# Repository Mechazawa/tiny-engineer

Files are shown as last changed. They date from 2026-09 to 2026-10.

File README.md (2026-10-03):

# Tiny Engineer

> Give your AI coding agent a body.

Tiny Engineer demo

**[Watch the demo](https://youtu.be/RX_QRxdXMjg)** · [Build your own](#build-your-own) · [Community builds](#community-builds) · [How it works](#how-it-works)

A small robot on your desk. It moves, changes its face, and rings a bell as your coding AI agent works.

| Your agent… | The robot… |
| --- | --- |
| Reads files | Looks around |
| Writes code | Types |
| Thinks or waits | Looks up |
| Finishes the task | Rings the bell |

Open source. Print the body, plug the ESP32, servos, OLED, and speaker into the [main control board](docs/hardware/main-control-board.md), flash it, and it joins your Wi-Fi.

**Works with** [Claude Code](docs/integration.md#4-claude-code-dedicated-script) · [Cursor](docs/hooks.md) · [Antigravity](docs/integration.md#3-antigravity-cli-dedicated-script) — or Codex, Windsurf, and any script that can POST ([integration guide](docs/integration.md)).

## Build your own

| | |
| --- | --- |
| **Parts (electronics + 5× SG90 Servos)** | [shopping list](docs/shopping.md): [main control board](docs/hardware/order-main-control-board.md) plus ESP32, servos, OLED, and speaker |
| **Also needed** | 3D printer + filament, or [order prints](docs/3d/order-parts.md); M2 screws; **5 V / ≥2 A** USB supply |
| **Tools** | Plug in the ESP32, servos, OLED, and speaker on the [main control board](docs/hardware/main-control-board.md). Want to add extra modules? [advanced wiring](docs/hardware/wiring.md) |
| **Difficulty** | **Medium** - fair first hardware project for a software engineer, not a one-LED kit. Optional primer: [From Code to Circuits](docs/hardware-for-software-engineers/README.md) |

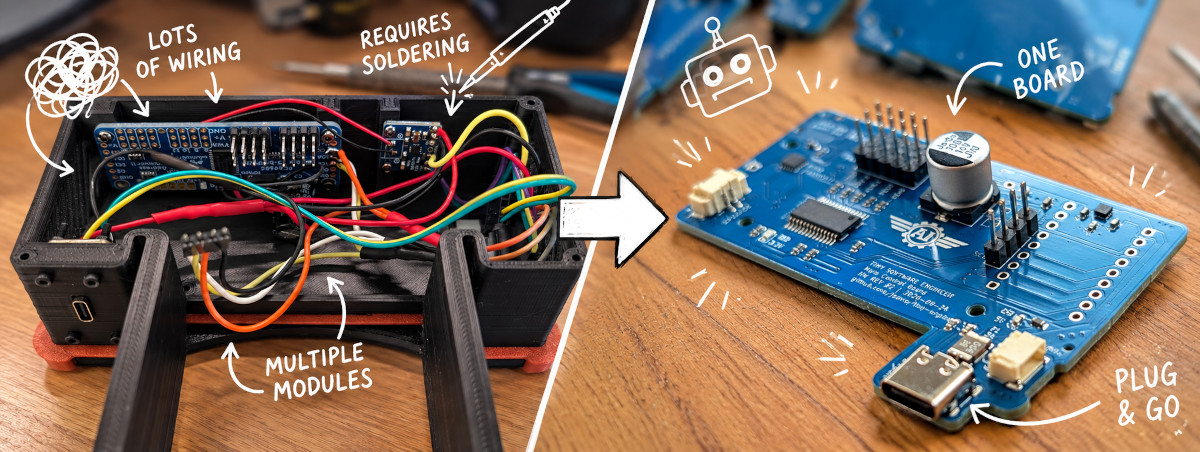
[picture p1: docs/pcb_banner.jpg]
Main control board (https://github.com/jamro/tiny-engineer/discussions/50)


The default build uses the open-source main control board. Order it from any fab ([how to order](docs/hardware/order-main-control-board.md) · [KiCad](hardware/boards/main-control-board/)). A ~$15–20 assembled board would be easier to buy. [Vote here 👍 →](https://github.com/jamro/tiny-engineer/discussions/50)

**Print → Connect → Flash → Assemble** - step-by-step: **[Getting started](docs/getting-started.md)**.

## Community builds

Built Tiny Engineer

Finished builds, mods, and desk setups live in **[Show and tell](https://github.com/jamro/tiny-engineer/discussions/categories/show-and-tell)** on GitHub Discussions - browse what others made and post photos of yours.

**Built one? [Share in Show and tell →](https://github.com/jamro/tiny-engineer/discussions/categories/show-and-tell)**

## Roadmap

What we are building toward:

- **More agent integrations** - one-command hooks for more IDEs and CLIs
- **Simplified build process** - easier assembly and setup for quicker builds
- **New characters / bodies** - alternate shells and mods
- **Multi-agent desk** - more than one tiny teammate

**[Star Tiny Engineer](https://github.com/jamro/tiny-engineer)** to follow the build.

## How it works

How Tiny Engineer works

Your agent (or a hook script) sends poses over HTTP. The **ESP32-C3** is a small Wi-Fi computer on the robot — one chip that runs the program, joins your network, hosts REST API, and drives the servos, the face, and the speaker.

**Clients**

- **Cursor** - hooks → `tiny-engineer-cursor` → Wi-Fi
- **Antigravity** - lifecycle hooks → `tiny-engineer-antigravity` → Wi-Fi
- **Claude Code** - project hooks → `tiny-engineer-claude-code` → Wi-Fi
- **Bring your own** - any tool that can `POST` to `/anim`

Details: [Integrations](docs/integration.md) · [HTTP API](docs/api.md) · [Cursor hooks](docs/hooks.md)

## Documentation

| You want to… | Start here |
| --- | --- |
| Build the robot | [Getting started](docs/getting-started.md) |
| Buy parts | [Shopping list](docs/shopping.md) |
| Flash the board | [Flash](docs/flash.md) |
| Assemble the prints | [Assembly](docs/3d/assembly.md) |
| Print the parts | [3D models](3d_models/README.md) |
| Hook up an agent | [Integrations](docs/integration.md) |
| Call the HTTP API | [API](docs/api.md) |
| Anything else | [Docs index](docs/README.md) |

Print it, connect it, change the CAD, or hook up another agent. Issues and PRs welcome - especially new integrations. [CONTRIBUTING.md](CONTRIBUTING.md) · [SECURITY.md](SECURITY.md) · [CODE_OF_CONDUCT.md](CODE_OF_CONDUCT.md)

## License

- **Software** (firmware, integrations, scripts, documentation) — [MIT](LICENSE)
- **Hardware designs** (CAD source and printables in [`3d_models/`](3d_models/) and under [`mods/*/3d_models/`](mods/); KiCad PCBs in [`hardware/`](hardware/)) — [CERN-OHL-S-2.0](3d_models/LICENSE)

See [LICENSING.md](LICENSING.md) for scope and effective date. The **Tiny Engineer** name and logo are not licensed - see [TRADEMARK.md](TRADEMARK.md).

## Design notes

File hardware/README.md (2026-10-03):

# Hardware (PCB)

KiCad PCB projects for Tiny Engineer. Builders: the main control board is the default electronics path — [shopping](../docs/shopping.md) and [connect guide](../docs/hardware/main-control-board.md). Breakout modules are an advanced path for extra hardware the board does not support — [wiring](../docs/hardware/wiring.md).

Boards live under `boards/<board-name>/`. Prefer the same name for the directory and the KiCad project.

| Board | Role |
| --- | --- |
| [`main-control-board`](boards/main-control-board/) | Main board: PCA9685, MAX98357A, and USB-C on the board; ESP32-C3-Zero plugs into two sockets |

Contribution rules, KiCad version, what to commit, ERC/DRC, and PR expectations: [docs/pcb.md](../docs/pcb.md). Pre-PR checklist: [docs/pcb.md#checklist](../docs/pcb.md#checklist). Critical net checklist: [docs/pcb.md#expected-netsyml](../docs/pcb.md#expected-netsyml). Local/CI checks: `python3 scripts/check_pcb.py` (KiCad 10) — [docs/testing.md](../docs/testing.md).

This tree is KiCad source only. Robot electrical reference (pinout, wiring, BOM) is [`docs/hardware/`](../docs/hardware/README.md). Firmware drivers are `src/hardware/`.

## License

Board sources in `boards/` are [CERN-OHL-S-2.0](LICENSE). See [NOTICE](NOTICE) for copyright, Source Location, and product notice requirements.

This README is software documentation and remains under the MIT License — [LICENSING.md](../LICENSING.md).

The **Tiny Engineer** name and logo are not licensed — [TRADEMARK.md](../TRADEMARK.md).

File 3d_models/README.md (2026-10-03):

# 3D models

Printable parts and source CAD for the Tiny Engineer desk robot.

## Source CAD (edit / resize)

The full assembly — all components composed — lives in [`cad/TinyEngineer.f3d`](cad/TinyEngineer.f3d) (Autodesk Fusion). Open that file to adjust the model or adapt it to different hardware sizing (e.g. different servos). Parametric servo sizes and the Fusion add-in: [docs/3d/parametric-design.md](../docs/3d/parametric-design.md).

**Adding a new part** (parametric rules, timeline, `PRINT_LAYOUT`, Servo Configurator, export, optional mods): [docs/3d/adding-parts.md](../docs/3d/adding-parts.md). Optional / community mods: [`mods/`](../mods/).

## Printables

Individual parts are exported under [`parts/{servo_id}/`](parts/). Match the folder to the servos you bought ([which servo](../docs/shopping.md)). `stl/` next to `3mf/` is the same mesh in binary STL. `step/` next to those is CAD interchange (BRep STEP), not a printable mesh for a home slicer.

Two ways to get the mechanical set (same place in the build path):

- **Print yourself** — use the **`.3mf` files in `parts/sg90/3mf/`**, **`parts/fs0307/3mf/`**, or **`parts/hd1370a/3mf/`**. Ready to print in an orientation that does not need supports. **PLA** or **PETG**. Start with [Print first](#print-first).
- **No printer?** — order the aggregated sets from a third-party service: [order printed parts](../docs/3d/order-parts.md). Orders are at your own risk; fit can vary by provider and design revision.

### Print first

**Home printers only.** Print these two small testers from that folder **before** the rest of the set. Do not print the full robot until both fit. Skip this step when ordering from a service (testers alone are rarely worth the min fee + shipping).

1. **`ServoSizingTester.3mf`** — seat a real servo; do not force it. The body should slide, tabs sit, holes line up, and the shaft should have clearance. Tight or loose → sand/ream, or adjust servo CAD params ([parametric design](../docs/3d/parametric-design.md)).
2. **`ScrewSizingTest.3mf`** — M2 screw pilot-hole tolerance. Each hole is marked with its diameter. Drive an M2 screw into each hole and pick the tightest size that still cuts a thread (does not spin freely / slide through). Set Fusion user parameter `screw_thread_diameter` to that marked value, then re-export before printing structural parts. Details: [M2 screw holes](../docs/3d/parametric-design.md#m2-screw-holes).

Assembly uses **M2 screws** that thread directly into the printed PLA/PETG — no glue, no heat-set inserts. Easy to dismount and modify later. Buyer cart (electronics + screw qty + supply): [docs/shopping.md](../docs/shopping.md). Overall build order: [docs/getting-started.md](../docs/getting-started.md). Mechanical procedure: [docs/3d/assembly.md](../docs/3d/assembly.md). Per-step lengths: [screw list](#screws) below.

### Screws

**Spec:** M2 thread-forming (self-tapping) screws for plastic, **pan-head or button-head** — heads normally sit on the plastic surface. `BottomCover` has recessed head pockets; use heads no larger than **4.0 mm diameter × 2.0 mm high** so the underside rests flat. CAD default pilot is **2.1 mm** (Fusion user parameter `screw_thread_diameter`); if your `ScrewSizingTest` winner differs, re-export at that diameter before printing structural parts. Details: [M2 screw holes](../docs/3d/parametric-design.md#m2-screw-holes).

**One BOM for every servo preset** (`parts/sg90/`, `parts/fs0307/`, `parts/hd1370a/`, …). Printed parts scale with the servo choice, but the lengths below are the reference list for all of them — including smaller models for smaller servos. Buy quantities: [docs/shopping.md](../docs/shopping.md). Pilots are cut as deep as practical so nearby lengths often work too; if you already have different M2 lengths, test-fit before buying a full set. Per-step placement: [assembly guide](../docs/3d/assembly.md).

**Per robot (qty is source of truth):**

| Item | Qty | Typical use |
| --- | --- | --- |
| M2×4 mm | 8 | Emblem, PCA9685, MAX98357A |
| M2×8 mm | 27 | Hat, Neck↔Head, Chest center (prefer two), Belly↔Chest, LampBase, laptop, mug, Chair↔Desk, elbows, BottomCover ×6 |
| M2×16 mm | 15 | Chest side servos, SeatLeft/Right, DeskTop stack, USB-C, Bell |
| M2 nuts | 6 | Neck captured ×1, USB-C ×4, Bell ×1 |
| Servo bag screws | 5 | Neck shaft, Neck↔Head (robot’s left), Belly shaft, both arms |

Prefer **two** M2×8 for the Neck servo in `Chest`; one at the back is enough if space is tight (buy 27 either way). An M2 assortment covering **M2×4–M2×16** is the easy path.

## Parts

Same filenames in each `parts/{servo_id}/3mf/` folder (and matching `stl/` / `step/`):

| File | Role |
| --- | --- |
| `PartsSetA.3mf` | Aggregated copper-color group for [service orders](../docs/3d/order-parts.md) (home print: use individuals below) |
| `PartsSetB.3mf` | Aggregated black-color group for [service orders](../docs/3d/order-parts.md) (home print: use individuals below) |
| `Head.3mf` | Head (pitch) |
| `Neck.3mf` | Neck (yaw) |
| `ForearmLeft.3mf` | Left forearm / hand |
| `ForearmRight.3mf` | Right forearm / hand |
| `UpperArm.3mf` | Upper arm |
| `Chest.3mf` | Chest / torso |
| `Belly.3mf` | Belly |
| `Chair.3mf` | Chair |
| `SeatLeft.3mf` | Left chair seat |
| `SeatRight.3mf` | Right chair seat |
| `Desk.3mf` | Desk structure |
| `BottomCover.3mf` | Underside cover; six M2×8 (four desk, two chair) |
| `DeskTop.3mf` | Desk top surface |
| `DeskPad.3mf` | Desk pad |
| `LaptopCase.3mf` | Miniature laptop body |
| `LaptopScreen.3mf` | Laptop screen |
| `Bell.3mf` | Service bell |
| `LampBase.3mf` | Desk lamp base |
| `LampCap.3mf` | Lamp cap |
| `LampDiffuser.3mf` | Lamp diffuser |
| `LampButton.3mf` | Lamp button |
| `Mug.3mf` | Mug |
| `Coffee.3mf` | Coffee fill |
| `Hat.3mf` | Hat |
| `ServoSizingTester.3mf` | Servo pocket fit tester |
| `ScrewSizingTest.3mf` | M2 screw pilot-hole diameter tester |
| `AiEmblem.3mf` | AI emblem detail |

## Next steps

Return to the build checklist: [docs/getting-started.md](../docs/getting-started.md) ([§2 Print or order](../docs/getting-started.md#2-print-or-order) done). Connect and flash **before** opening the mechanical guide.

1. Connect, then flash: [docs/hardware/main-control-board.md](../docs/hardware/main-control-board.md), [docs/flash.md](../docs/flash.md). Extra modules: [docs/hardware/wiring.md](../docs/hardware/wiring.md)
2. Assemble in one run: [docs/3d/assembly.md](../docs/3d/assembly.md)
3. Servo axes and safe ranges: [docs/robot-movement.md](../docs/robot-movement.md)
4. Bring-up and failures: [docs/hardware/testing.md](../docs/hardware/testing.md)

## License

CAD source (`.f3d`) in [`cad/`](cad/) and printable parts (`.3mf`) in [`parts/`](parts/) are licensed under [CERN-OHL-S-2.0](LICENSE). See [NOTICE](NOTICE) for copyright, Source Location, and product notice requirements.

Commercial use is allowed. If you modify and distribute Products based on these designs, reciprocal provisions require sharing your Complete Source under the same license. This documentation file is software documentation and remains under the MIT License — see [LICENSING.md](../LICENSING.md).

The **Tiny Engineer** name and logo are not licensed — see [TRADEMARK.md](../TRADEMARK.md).

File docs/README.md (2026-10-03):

# Docs index

Pick a path. Depth lives in the linked pages.

### Building the robot

| You want to… | Start here |
| --- | --- |
| **Build from scratch** (canonical checklist) | [getting-started.md](getting-started.md) |
| **Buy parts** (main control board + cart) | [shopping.md](shopping.md) |
| **Bridge into hardware/electronics** (software engineer background) | [hardware-for-software-engineers/README.md](hardware-for-software-engineers/README.md) — optional parallel reading; safety card lives on the checklist |
| **Assemble printed parts** (mechanical procedure) | [3d/assembly.md](3d/assembly.md) |
| **Flash firmware** | [flash.md](flash.md) |
| **Electronics** (main control board) | [shopping.md](shopping.md) → [hardware/main-control-board.md](hardware/main-control-board.md) → [hardware/README.md](hardware/README.md) |
| **Extra modules** (advanced breakouts) | [shopping.md](shopping.md#advanced-extra-modules) → [hardware/wiring.md](hardware/wiring.md) → [3d/assembly-modular.md](3d/assembly-modular.md) |
| **Print / parts inventory** | [../3d_models/README.md](../3d_models/README.md) |
| **Order printed parts** (no 3D printer) | [3d/order-parts.md](3d/order-parts.md) |
| **Order main control board** (PCB / PCBA) | [hardware/order-main-control-board.md](hardware/order-main-control-board.md) |
| **Adapt CAD to a different servo** | [3d/parametric-design.md](3d/parametric-design.md) |
| **Add a new CAD / printable part** | [3d/adding-parts.md](3d/adding-parts.md) |
| **Optional mods** | [../mods/README.md](../mods/README.md) |
| **Use with an agent** (robot already on Wi-Fi) | [integration.md](integration.md) · Cursor: [hooks.md](hooks.md) |

### Reference and contribute

| You want to… | Start here |
| --- | --- |
| **Contribute a PCB** (KiCad) | [pcb.md](pcb.md) → [`hardware/`](../hardware/README.md) |
| **HTTP API / settings** | [api.md](api.md); add a setting: [settings.md](settings.md) |
| **Any IDE / scripts** | [integration.md](integration.md) |
| **Firmware / package tests** | [testing.md](testing.md) |
| **AI coding agents (repo rules)** | [AGENTS.md](../AGENTS.md) |
| **Contribute / report a vuln** | [CONTRIBUTING.md](../CONTRIBUTING.md); [SECURITY.md](../SECURITY.md) |
| **Share a finished build** | [Show and tell](https://github.com/jamro/tiny-engineer/discussions/categories/show-and-tell) — [how to post](../CONTRIBUTING.md#share-your-build) |

Also: [robot-movement.md](robot-movement.md) (servo axes and safe ranges); optional [macos-lock-unlock.md](macos-lock-unlock.md) (sleep/wake on Mac screen lock).

**Source of truth:** pin constants in firmware (`include/pins.h`); electrical detail in `docs/hardware/`; HTTP shapes in [api.md](api.md). Overall build order: [getting-started.md](getting-started.md).

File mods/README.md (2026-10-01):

# Mods

Optional add-ons for Tiny Engineer. Stock robot parts live in [`3d_models/`](../3d_models/).

A mod can hold models and anything else (notes, images, firmware snippets). Printable geometry and Fusion source stay under that mod’s `3d_models/` folder.

## Layout

```text
mods/<mod_name>/
  README.md              # optional: what it is, non-model notes
  3d_models/
    cad/                 # Fusion source, when the mod has one
    parts/{servo_id}/    # exports; same idea as 3d_models/parts/
  ...                    # anything that is not a model
```

`parts/{servo_id}/` mirrors stock: `3mf/`, `stl/`, and `step/`. Example: [`halloween/`](halloween/).

## Audio

Optional speaker replacements live in `mods/<mod_name>/assets/`. Format matches stock: **44100 Hz, mono, 16-bit PCM**. Firmware still plays `/welcome.wav` and the other root names. The build overlay copies stock [`assets/`](../assets/) first, then overwrites any basename the mod ships. A missing file stays the stock clip.

Set the mod in [`platformio.ini`](../platformio.ini) (`custom_audio_mod = halloween`) and flash with `pio run -t upload`. An empty option keeps the stock image. How to flash: [docs/flash.md](../docs/flash.md).

Clips with phrase marks (`welcome`, `attention`, `error`, `abort`, `dead`) need a sibling `.cue` next to the replacement WAV. `bell` has no marks. A cue without its WAV is rejected. Lines are `key=ms` (`#` comments allowed). `end_ms` must be within 200 ms of the WAV duration, phases must increase, and a blink must sit inside its window. The pack step checks this before the image is built.

Firmware loads `/welcome.cue` (and the other clip names) from LittleFS at boot. A missing or invalid file keeps the stock marks compiled into the firmware. Editing a `.cue` and running `pio run -t uploadfs` changes timing without a gesture-code change.

| Clip | Keys, in phase order |
| --- | --- |
| `welcome` | `greeting_end_ms`, `pause_end_ms`, `question_end_ms`, `end_ms`. Blink: `blink_start_ms`, `blink_end_ms` inside greeting→pause. |
| `attention` | `pst_end_ms`, `human_end_ms`, `end_ms`. Blink inside pst→human. |
| `error` | `uhoh_end_ms`, `human_end_ms`, `problem_end_ms`, `end_ms` |
| `abort` | `fine_end_ms`, `didnt_want_end_ms`, `finish_end_ms`, `end_ms` |
| `dead` | `dense_ms`, `shutdown_ms`, `end_ms` |

## Workflow

Design, timeline, `PRINT_LAYOUT`, export, and checklist: [docs/3d/adding-parts.md](../docs/3d/adding-parts.md).

## Commits

`type(mods): summary`. Name the mod in the summary (`feat(mods): add desk clamp`). One scope for every mod. `feat(mods)` / `fix(mods)` do not version the stock CAD revision. Moving a mod into stock [`3d_models/cad/`](../3d_models/cad/) and [`3d_models/parts/`](../3d_models/parts/) is `feat(cad)`. Full rules: [CONTRIBUTING.md](../CONTRIBUTING.md).

## License

CAD and manufacturing exports under `mods/<mod_name>/3d_models/{cad,parts}/` are [CERN-OHL-S-2.0](../3d_models/LICENSE). See [NOTICE](../3d_models/NOTICE) for warranty and product-notice requirements.

When you distribute a Product based on a mod, cite that licence and use the mod’s own `3d_models` tree as the Source Location (for example `https://github.com/jamro/tiny-engineer/tree/main/mods/halloween/3d_models`).

This README and other files beside `3d_models/` are documentation under the [MIT License](../LICENSE).

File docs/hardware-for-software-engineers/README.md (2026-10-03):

# From Code to Circuits: Hardware for Software Engineers

*Learn electronics and physical builds through Tiny Engineer — a desk robot that's fun to finish and honest about real hardware.*

I wrote this because software engineers keep asking how to build Tiny Engineer when they've never touched the hardware side — what's a servo driver, why two voltages, whether they'll destroy the board on first power-on. The build docs tell you *what to connect*; this guide answers the questions behind them.

---

## Goal

**Bring the world of electronics and hardware closer to software engineers** — especially the ones showing up with Tiny Engineer parts and no hardware background.

If you live in code, hardware docs can feel like a foreign API with no types and no stack traces. This guide closes that gap: same systems thinking you already use — buses, power budgets, failure modes — applied to volts, GPIO, and printed plastic. It's the long-form version of answers I give when someone says *"I'm a developer, I just want the robot to work."*

**Why now:** AI makes writing code fast and cheap. Hardware stays tangible, constrained, and extremely satisfying when something on your desk actually moves because *you* wired it.

**Why Tiny Engineer as the example:** one coherent stack (MCU, I2C, I2S, power domains, 3D print, servos) — real enough to teach honest hardware, bounded enough to finish if you stick with it. It also ties back to software via Wi-Fi and HTTP, which helps the mental bridge.

**What you'll get out of it:** read datasheets, schematics, and embedded docs without feeling like an outsider — whether you build this robot or the next board on your bench.

**Honest expectation:** Tiny Engineer was never meant to be an entry-level electronics kit (no single-LED breadboard tutorial). Overall difficulty is **medium**. It can still be your **first hardware project** as a software engineer — if you read alongside the build, smoke-test the main control board on the desk (connect + flash) before closing the shell, and don't treat "first" as "trivial." Harness examples later in this guide are the advanced path for extra modules — [wiring.md](../hardware/wiring.md). See [difficulty by area](#honest-difficulty-by-area) below.

---

I'm a software engineer. I got into hardware and electronics long before Tiny Engineer — out of curiosity, because I find it fun, and because making something *physical* work hits different from shipping another service. I'm not an EE. I've smelled the regret breadboard too; I've also had plenty of projects since then that actually moved and blinked.

Tiny Engineer is one project in that line. I'd recommend this path to any software engineer: learn the basics, wire something on a bench, watch it do a thing you commanded. Especially now, when a servo buzzes because you misaligned a horn — not because a model hallucinated a pin number — you learn something no codegen session replaces.

**What this is:** a bridge into electronics, microcontrollers, power, protocols, and mechanical build craft — taught with software-engineer mental models.

**What this is not:** only a Tiny Engineer assembly manual. When you're ready to build step by step, use [getting-started.md](../getting-started.md) (checklist), [flash.md](../flash.md), and the [hardware reference](../hardware/README.md).

---

## Why Tiny Engineer is the example

Every chapter teaches a **general concept**, then shows **where it lands in this build**. Tiny Engineer gives you real constraints — 3.3 V vs 5 V domains, shared I2C, offloaded servo PWM, print tolerances, antenna keep-out — without throwing you into a parts warehouse with no narrative. Finish the robot if you want the payoff; the vocabulary transfers to other ESP32, Arduino, or IoT projects either way.

It's a good **first hardware project for a software engineer**. It is **not** a good **first project in electronics** in the abstract — compare it to a blinking-LED kit and this is several notches up. This guide exists because those two truths collide constantly in questions from SWEs who want to build the robot anyway.

---

## Honest difficulty by area

Rough levels: **Easy** · **Medium** · **Medium–High** (for someone with no prior hardware builds). Overall build: **Medium**.

| Area | Level | Why |
| --- | --- | --- |
| [Electricity & power domains](01-electricity-and-units.md) | Medium | Two voltage rails, common GND, VCC vs V+ — mistakes fry boards, not just fail tests |
| [Microcontrollers & ESP32](02-microcontrollers-and-esp32.md) | Medium | Wi-Fi MCU, native USB, scarce GPIO, flash/LittleFS — more moving parts than Arduino Uno 101 |
| [Wiring & schematics](03-wiring-craft-and-schematics.md) | Medium–High | Default board is plug-in. The advanced harness is six-ish modules, many nets, classic traps (swapped I2C, speaker on GND) |
| [Buses: I2C, I2S, PWM](04-buses-and-protocols.md) | Medium | Three protocol types in one device; standard hobby stack, but not "one wire one LED" |
| [Servos & mechanical motion](05-servos-and-mechanical-motion.md) | Medium–High | Five joints, horn alignment, mechanical limits, binding/stall — software clamps can't fix physics |
| [3D printing & mechanical build](06-3d-printing-and-mechanical-build.md) | Medium | Many printed parts, tolerances, partial assembly docs; optional Fusion edits add learning curve |
| [Power budgets & safety](07-power-budgets-and-safety.md) | Medium | Real stall currents (~1.3–1.6 A), supply sizing, brownout debugging |
| [Embedded workflow & debug](08-tools-debugging-and-embedded-workflow.md) | Medium *(lower if you live in CLI)* | PlatformIO, serial, bisect bring-up — familiar shape for SWEs, unfamiliar failure modes |
| REST / Wi-Fi / agent hooks | Easy *(for SWEs)* | HTTP you already know — **after** hardware works |

**What makes it medium, not beginner-kit:**
- Multiple ICs on shared buses, not one chip
- Motor power + logic power discipline
- Mechanical assembly with real tolerances
- Debug requires dividing hardware vs software

**What makes it viable as a first SWE hardware project:**
- Documented BOM, wiring, firmware — not a blank breadboard
- Software-shaped affordances: serial logs, HTTP `/test/*`, web UI
- This guide translates concepts into your vocabulary first
- Finish line is motivating (desk robot, not only a blinking LED)

If you've never touched a multimeter, budget extra time on [Ch. 01](01-electricity-and-units.md), [Ch. 07](07-power-budgets-and-safety.md), and bring-up discipline in [Ch. 08](08-tools-debugging-and-embedded-workflow.md). Skipping straight to "assemble everything and flash" (or closing the chest before desk smoke) is how medium projects feel hard.

---

## Who should read this

**Read this if you:**
- Write code for a living and want to build Tiny Engineer (or similar) without a hardware background
- Got the parts or the repo and hit questions the assembly docs don't pause to explain
- Know what HTTP is but not what I2C is
- Can follow a tutorial but want to understand what you're doing
- Are curious about embedded, IoT, or physical computing — even if you've never soldered

**Skip this if you:**
- Already own a multimeter and use words like "pull-up" without Googling
- Have built an ESP32 project before and just need the BOM — go to [shopping.md](../shopping.md) and [getting-started.md](../getting-started.md)

**Don't skip the difficulty section** if this is your first hardware build — [Honest difficulty by area](#honest-difficulty-by-area) sets expectations.

---

## How this fits the rest of the docs

There are three layers. Read them in order when you're learning; jump to the right layer when you know what you need.

```mermaid
flowchart LR
  primer["hardware-for-software-engineers\n(concepts)"]
  build["getting-started.md\n(checklist)"]
  ref["hardware/\n(reference)"]

  primer -->|"understand why"| build
  build -->|"look up details"| ref
```

| Layer | When to use it |
| --- | --- |
| **This guide** | Bridging hardware/electronics concepts from a software background |
| **[getting-started.md](../getting-started.md)** | Canonical build checklist (open leaf docs, return) |
| **[hardware/](../hardware/README.md)** / [flash.md](../flash.md) | Looking up pins, wiring, power, flash, test procedures |

---

## Reading order

**Alongside the checklist** if hardware is new — print while you read; do not finish this guide before [getting-started.md](../getting-started.md):

1. [Electricity and units](01-electricity-and-units.md)
2. [Microcontrollers and ESP32](02-microcontrollers-and-esp32.md)
3. [Wiring craft and schematics](03-wiring-craft-and-schematics.md)
4. [Buses and protocols](04-buses-and-protocols.md)
5. [Servos and mechanical motion](05-servos-and-mechanical-motion.md)
6. [3D printing and mechanical build](06-3d-printing-and-mechanical-build.md)
7. [Power budgets and safety](07-power-budgets-and-safety.md)
8. [Tools, debugging, and embedded workflow](08-tools-debugging-and-embedded-workflow.md)
9. [How it all fits together](09-how-it-all-fits-together.md)

**Shortcuts** — where universal concepts land in this build; jump to one chapter if you only need that topic:

| You need to understand… | Read |
| --- | --- |
| ESP32-C3-Zero, GPIO, USB, antenna | [Ch. 02](02-microcontrollers-and-esp32.md) |
| 3.3 V vs 5 V, LDO, VCC vs V+ | [Ch. 01](01-electricity-and-units.md) + [Ch. 07](07-power-budgets-and-safety.md) |
| I2C (OLED + PCA9685) | [Ch. 04](04-buses-and-protocols.md) |
| I2S (audio) | [Ch. 04](04-buses-and-protocols.md) |
| Servo PWM chain | [Ch. 04](04-buses-and-protocols.md) + [Ch. 05](05-servos-and-mechanical-motion.md) |
| Fusion CAD edits | [Ch. 06](06-3d-printing-and-mechanical-build.md) |
| PLA vs PETG | [Ch. 06](06-3d-printing-and-mechanical-build.md) |

---

## Mini glossary

Terms you'll see everywhere. Each chapter goes deeper. Think of these as hardware concepts translated into software-shaped words.

| Term | One-line meaning |
| --- | --- |
| **MCU** | The chip that runs your firmware — like a tiny server that boots straight into one binary (no OS, no SSH). Here: ESP32-C3 |
| **GPIO** | A pin the firmware can drive or read — hardware I/O endpoints, not USB or Wi-Fi |
| **GND** | Shared **0 V reference** for every module — like agreeing on one clock/time base; without it, nothing can talk reliably |
| **3.3 V / 5 V** | **Signal voltage** (3.3 V, ESP32-safe) vs **power rail** (5 V, servos/amp) — two different numbers; don't mix them up |
| **LDO** | Onboard **5 V → 3.3 V converter** for logic chips — sized for milliamps, not motors |
| **I2C** | Two-wire **request/response bus** — each chip has an address (`0x40`, `0x3C`); ESP32 is the only master |
| **I2S** | **Streaming audio bus** — continuous PCM samples over wires, like a one-way socket, not I2C-style reads |
| **PWM** | A pin toggling on/off on a schedule — servos read **pulse length** inside each cycle as "go to this angle" |
| **Brownout** | Power sags → chip **hard-resets** — feels like a random reboot, often when servos or audio spike current |
| **PCA9685** | **Servo PWM co-processor** — ESP32 sends angles over I2C; this chip generates the precise 50 Hz pulses |

---

## When you're ready to build

You've read enough when you can explain in plain language:

- Why servos don't get power from the ESP32's 3.3 V pin
- What I2C and I2S do on this robot (and that they're different)
- Why there's a separate PCA9685 chip instead of "just PWM in code"
- Where the ceramic antenna is and why you shouldn't bury it in plastic

**Minimum skim before power:** [Ch. 01](01-electricity-and-units.md) and [Ch. 07](07-power-budgets-and-safety.md) (3.3 V vs 5 V, VCC ≠ V+). This guide is **parallel reading**, not a prerequisite. Jump to one chapter from the shortcuts table if you only need that topic.

Then open [getting-started.md](../getting-started.md) and work the checklist (shop → print → connect → flash → assemble → wizard → prove).

**Reference:** [getting-started.md](../getting-started.md) · [hardware/README.md](../hardware/README.md) · [3d_models/README.md](../../3d_models/README.md)

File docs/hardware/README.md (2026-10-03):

# Tiny Engineer — hardware overview

Canonical hardware reference for the Tiny Engineer robot.

Firmware pin constants live in [`include/pins.h`](../../include/pins.h). The default build is the **main control board** ([main-control-board.md](main-control-board.md)). The advanced path wires separate breakouts ([wiring.md](wiring.md) + drawio) when you add modules the board does not support. Same nets and firmware.

Source of truth: firmware `include/pins.h`, then this `docs/hardware/` set. Modular topology: `docs/wiring/`. PCB connectivity: board `expected-nets.yml` / netlist per [pcb.md](../pcb.md).

| Audience | Use this set for |
| --- | --- |
| Human | Assembly, wiring, power, bring-up, debugging |
| Firmware agent | Pin map, buses, voltages, servo PWM conventions, test sequence |

## Purpose

Small desktop robot with:

- 5 analog micro servos (head, neck, hands, body — [robot-movement.md](../robot-movement.md))
- I2C OLED status display
- I2S speaker for tones and WAV playback
- ESP32-C3 Wi-Fi for HTTP control and AI hooks

Firmware (`src/main.cpp`) is the robot application: Wi-Fi, settings, hardware tests, animations, and the JSON API.

## Hardware architecture

One ESP32-C3 module owns all logic. Servo PWM is offloaded to a PCA9685 so pulse generation does not depend on ESP32 timing. Audio is I2S into a class-D amp. Display and servo driver share one I2C bus. On the default build those chips are on the main control board. The advanced path puts the same chips on breakouts — the diagram is the same either way.

```mermaid
flowchart TB
  USB["USB 5V / GND<br/>as drawn"]

  subgraph p5["5 V power domain"]
    ESP5["ESP32 5V"]
    PCA5["PCA9685 5V"]
    PCAVplus["PCA9685 V+"]
    MAXVIN["MAX98357A Vin"]
    SERVOS["Servo 5V"]
  end

  subgraph p33["3.3 V logic domain"]
    ESP["ESP32-C3-Zero"]
    PCA["PCA9685 VCC"]
    OLED["OLED VCC"]
  end

  USB -->|"5V"| ESP5
  USB -->|"5V"| PCA5
  USB -->|"5V"| MAXVIN
  PCA5 --> PCAVplus
  PCAVplus --> SERVOS
  ESP5 --> ESP
  ESP -->|"3V3"| PCA
  ESP -->|"3V3"| OLED
  ESP -->|"GP0 SDA / GP1 SCL"| PCA
  ESP -->|"GP0 SDA / GP1 SCL"| OLED
  ESP -->|"GP2 BCLK / GP3 LRC / GP4 DIN"| MAXVIN
  PCA -->|"PWM"| SERVOS
```

Speaker **SPK+/SPK-**: [main-control-board.md](main-control-board.md). The modular PNG omits them — [wiring.md](wiring.md#not-on-the-drawing).

| Domain | Voltage | What lives there |
| --- | --- | --- |
| Power rail | **+5V** | USB **5V** → ESP32 **5V**, PCA9685 **5V**, MAX98357A **Vin**; PCA9685 **V+** → servo **5V** |
| Logic | **3V3** | ESP32 GPIO, PCA9685 **VCC**, OLED **VCC**, I2C, I2S |
| Ground | **GND** | Every module — common ground is mandatory |

> [!WARNING]
> Never power the servos from the ESP32 3.3 V regulator.

> [!WARNING]
> MAX98357A SPK- is not ground. Speaker connects between SPK+ and SPK- only.

## Major components

| Role | Main control board (default) | Advanced breakouts | Qty |
| --- | --- | --- | --- |
| Controller | Waveshare ESP32-C3-Zero (plugs into board sockets) | same | 1 |
| Servo PWM | PCA9685 on PCB | Adafruit PCA9685 breakout | 1 |
| Actuators | Analog micro servos — **Tower Pro SG90 recommended**; Feetech FS0307 compact; PowerHD HD-1370A still supported | same | 5 |
| Audio amp | MAX98357A on PCB | MAX98357A breakout | 1 |
| Speaker | [Adafruit Mini Oval Speaker - 8 Ohm 1 Watt](https://www.adafruit.com/product/3923) | same | 1 |
| Display | [Waveshare 0.91inch OLED Module](https://www.waveshare.com/0.91inch-oled-module.htm) (SSD1306, 128×32, I2C) | same | 1 |
| Robot USB | USB-C on PCB | Adafruit 5993 USB-C breakout | 1 |

Carts: [shopping.md](../shopping.md). Spec detail: [components.md](components.md). Connect: [main-control-board.md](main-control-board.md).

## Communication buses

| Bus | ESP32 pins | Devices |
| --- | --- | --- |
| I2C | GP0/SDA, GP1/SCL (Waveshare OLED **SCL**) | PCA9685 `0x40`, SSD1306 `0x3C` |
| I2S | GP2/BCLK, GP3/LRC, GP4/DIN | MAX98357A |
| Servo PWM | *(none on ESP32)* | PCA9685 channels 0–4 @ 50 Hz |
| USB | Board USB-C (VBUS/GND + D+/D− → GP19/GP18). Advanced path: 5993 — [wiring.md](wiring.md) | Power, flash, serial CDC |

Details: [interfaces.md](interfaces.md), [pinout.md](pinout.md).

## Power architecture

Single nominal **+5V** supply via the main control board USB-C. ESP32 onboard LDO makes **3V3** for logic only. PCA9685 **V+** (servos) is electrically separate from PCA9685 **VCC** (logic). The advanced path brings 5 V in through an Adafruit 5993 — [wiring.md](wiring.md).

Prefer a **5 V / ≥2 A** source with margin. Details: [power.md](power.md).

## Documentation map

| File | Contents |
| --- | --- |
| [../shopping.md](../shopping.md) | Default cart; advanced extra modules |
| [main-control-board.md](main-control-board.md) | Default connect: ESP32, OLED, servos, speaker |
| [order-main-control-board.md](order-main-control-board.md) | Order the PCB / PCBA (any fab; JLCPCB walkthrough) |
| [components.md](components.md) | Inventory, voltages, limits |
| [pinout.md](pinout.md) | GPIO map + allocation rules |
| [wiring.md](wiring.md) | Advanced: breakout harness |
| [../3d/assembly-modular.md](../3d/assembly-modular.md) | Advanced: mount breakouts in the desk |
| [power.md](power.md) | Budget, brownout symptoms, single-USB policy |
| [servos.md](servos.md) | PWM, test limits, safe ranges |
| [interfaces.md](interfaces.md) | I2C / I2S / PWM / USB |
| [testing.md](testing.md) | Bring-up sequence, failures, what to check |

Modular schematic sketch: [`docs/wiring/Tiny Engineer.drawio`](../wiring/Tiny%20Engineer.drawio) / [PNG](../wiring/Tiny%20Engineer.drawio.png). KiCad: [`hardware/boards/`](../../hardware/README.md); contribution rules: [`docs/pcb.md`](../pcb.md).

## Source-of-truth order

1. Repository firmware / `include/pins.h`
2. This `docs/hardware/` set; modular nets also in `docs/wiring/`; PCB nets via board expected-nets / netlist
3. Component datasheets

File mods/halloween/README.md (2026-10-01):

# Halloween

Optional Halloween mod for Tiny Engineer. [`3d_models/`](3d_models/) holds alternate versions of the **head**, **lamp**, and **mug**, plus a **standalone pumpkin** you can print in any amount and place next to the desk. Printables and Fusion source live under `3d_models/parts/{servo_id}/` (same servo folders as stock).

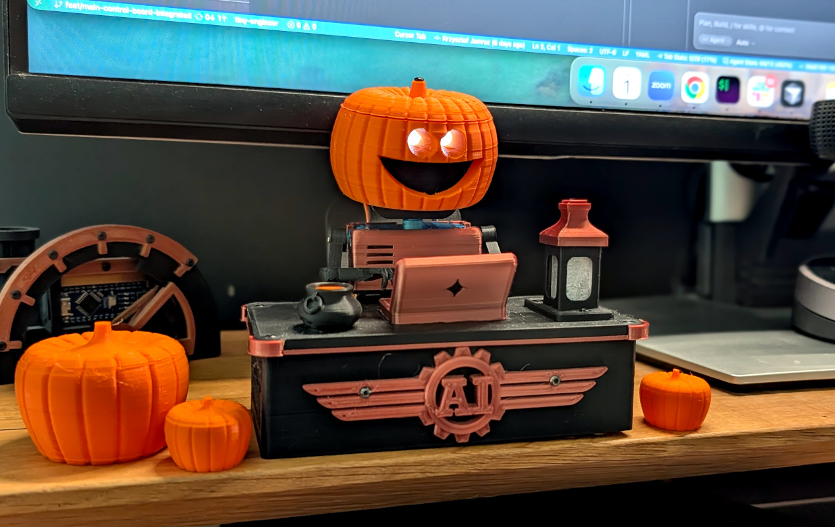
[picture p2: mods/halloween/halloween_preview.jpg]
Halloween mod parts


## Parts

| Role | Files |
| --- | --- |
| Head | `Head`, `PumpkinTop`, `PumpkinCover` |
| Lamp | `LampBase`, `LampDiffuser`, `LampCap` |
| Mug | `Pot`, `Mixture` (replaces stock `Mug` / `Coffee`) |
| Standalone | `Pumpkin` (decorative; not mounted on the robot) |

## Head assembly

The head is three parts. `Head` is the servo holder — mount it like the stock head component first and have it on the robot before you continue. Shared mechanical steps (servo, neck join): [docs/3d/assembly.md](../../docs/3d/assembly.md) (§1 Head, §4 Join Neck and Head).

1. Mount `Head` on the robot (servo in the holder) the same way as the regular `Head`. Finish this before the pumpkin shell.
2. Screw `PumpkinTop` into `PumpkinCover`.
3. Seat the OLED in `PumpkinCover`, then slide the cover onto the `Head` already on the robot.
4. Route the servo and OLED cords through the two side slots on the back of the head.
5. Optionally fasten the cover to `Head` with an M2 screw — there is a mount hole on the back.

## Lamp and mug

Mount the lamp and mug the same way as the stock parts. Lamp: [assembly §13](../../docs/3d/assembly.md#13-esp32-powerap-smoke-test-and-lampbase) (`LampBase`) and [§19](../../docs/3d/assembly.md#19-lamp-press-fit) (`LampCap` / `LampDiffuser`). Mug: [assembly §14](../../docs/3d/assembly.md#14-desk-props--laptop-mug-bell) — use `Pot` and `Mixture` in place of `Mug` and `Coffee`.

## Standalone pumpkin

Print `Pumpkin` as a desk prop. Scale it freely, or print several in different sizes, and place them next to the desk.

## Audio

Alternate speaker clips are in [`assets/`](assets/). The set replaces `welcome`, `attention`, `error`, and `abort`. `bell` and `dead` stay the stock files. Transcripts and cue marks are in [`assets/README.md`](assets/README.md).

Build and flash this overlay with `custom_audio_mod = halloween` in [`platformio.ini`](../../platformio.ini), then `pio run -t upload`. See [docs/flash.md](../../docs/flash.md).

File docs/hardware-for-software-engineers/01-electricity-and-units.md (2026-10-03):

# Electricity and units

Before you touch a wire, you need a shared vocabulary. Hardware docs throw around V, A, Ω, and GND like everyone took a circuits class. You didn't — that's fine. This chapter gets you to "I know what could kill my board." Every embedded project has power rails and a common ground; Tiny Engineer is a clear example of **two voltage domains** on one USB cable.

---

## Voltage, current, resistance, power

Four quantities. You'll see them on every datasheet.

| Quantity | Unit | What it means (intuition) |
| --- | --- | --- |
| **Voltage (V)** | Volts | Electrical "pressure" — how hard electrons are being pushed |
| **Current (I)** | Amperes (amps) | Flow rate — how many electrons per second |
| **Resistance (R)** | Ohms (Ω) | How much something resists flow |
| **Power (P)** | Watts (W) | Energy used per second — P ≈ V × I |

> **If you've written backend code…** Voltage is like request pressure on a queue. Current is throughput. Resistance is backpressure. Power is your AWS bill when both spike at once.

**Ohm's law** (you don't need to derive it): V = I × R. If you push harder (more V) through the same resistance, more current flows. Thin wire = more R = less I for the same V.

---

## DC vs AC

**DC (direct current):** voltage stays one way, like a battery. Tiny Engineer runs on **5 V DC** from USB.

**AC (alternating current):** voltage flips direction — wall outlets, 50/60 Hz. Not relevant inside the robot except that your USB charger converts AC to DC before the robot ever sees it.

---

## What "ground" (GND) actually is

GND is not a magical sink into the earth. It's a **shared reference point** that every device agrees is "zero volts."

All signals are measured *relative to GND*. If two boards don't share GND, their "high" and "low" mean nothing to each other — like two services with no common schema.

**Rule:** Connect all GND pins together. One common ground net for the whole robot.

---

## Series and parallel (just enough)

**Series:** components in a chain — same current flows through all of them.

**Parallel:** components side by side — same voltage across each branch; current splits.

Your five servos are **parallel** on the 5 V rail: each gets 5 V, and current adds up. That's why five servos can pull ~1.3 A together and overwhelm a weak USB port.

---

## Shorts, reversed polarity, and smoke

Three ways beginners destroy boards. Each is a **wiring mistake**, not a firmware bug — the code may never run.

### Short circuit — power wired straight to ground

**What it is:** `+5V` and `GND` connected with **almost no resistance** between them — a bare wire, a loose strand, a metal tool, a solder bridge.

**What happens:** Current spikes (Ohm's law: low R → huge I). Wires heat. USB port or regulator shuts off — or something burns. The chip may die instantly.

**What it looks like:** Instant. Sometimes smell. Board never boots. Multimeter beep between 5V and GND *before* power-on = stop and fix wiring.

> **Software analogy:** Like routing all traffic to `/dev/null` with infinite concurrency — the system doesn't degrade gracefully; something upstream trips hard.

**Common causes while wiring:** twisted red/black leads, frayed insulation, screwdriver slip, VCC accidentally tied to GND on a breakout.

### Reversed polarity — + and − swapped

**What it is:** Power connected **backwards** — positive where ground should be, ground where positive should be.

**What happens:** Depends on the board. Some breakouts have protection diodes; many don't. Best case: nothing until you fix it. Worst case: dead regulator, dead MCU, dead module.

**Rule:** Match labels on the diagram (`5V`, `VCC`, `Vin`, `GND`). Red-ish often means positive; black/brown often means ground — **verify**, don't guess from habit alone.

> **Don't "test" reversal on purpose.** Fix orientation before first power-on.

### Logic overvoltage — 5 V on a 3.3 V GPIO pin

**What it is:** Driving **5 V into an ESP32 GPIO** that only tolerates **3.3 V**. Different from powering the whole board at 5 V through its proper **5V** input pad (that path goes through the onboard regulator).

**What happens:** Input protection may clamp once; repeated or sustained overvoltage **damages the pin or the chip**. Behavior becomes erratic; pin may die silently.

**On Tiny Engineer:** I2C, I2S, and servo **signal** lines are 3.3 V logic. Servo **motor power** is 5 V on the red wire — that goes to PCA9685 **V+**, not to an ESP32 GPIO.

> **Software analogy:** Sending a payload the parser never validated — undefined behavior, often permanent. No try/catch on the silicon.

### Quick reference

| Mistake | You literally did | Typical result |
| --- | --- | --- |
| **Short** | Connected +5V to GND directly | Huge current, heat, dead supply path or board |
| **Reversed polarity** | Swapped power + and − on a module | Dead module or MCU — may be instant |
| **Logic overvoltage** | 5 V signal into ESP32 GPIO / 3.3 V input | Damaged pin or chip — flaky then dead |

**Before first power-on:** visual check, then continuity test (power **off**) — no beep between 5V and GND; every module's GND tied together. Assembly checks: [wiring.md](../hardware/wiring.md).

---

## 3.3 V, 5 V, and ones and zeros

In code you think in **bits**: `0` and `1`, `true` and `false`, `LOW` and `HIGH`. On a GPIO pin that is **not abstract** — the chip **holds the wire at a voltage** relative to GND:

| Logic (firmware) | Typical voltage on ESP32 pin | Meaning |
| --- | --- | --- |
| **0** / `LOW` / `false` | ~**0 V** (near GND) | "Pull the line down" |
| **1** / `HIGH` / `true` | ~**3.3 V** | "Pull the line up" |

So **3.3 V is the "one" voltage** on this robot's logic wires. A **zero** is not a separate negative voltage — it's "close enough to ground."

> **If you've written backend code…** GND is 0.0; a logic **1** is ~3.3 — like a boolean with a defined numeric encoding on the wire. I2C and I2S don't send JSON; they toggle and stream voltages that the other chip interprets as bits.

### Two different jobs — don't confuse them

| | **3.3 V (logic domain)** | **5 V (power domain)** |
| --- | --- | --- |
| **Role** | Encode **0s and 1s**; run logic chips at their rated voltage | **Deliver energy** — motors, audio amp, board power input |
| **On Tiny Engineer** | ESP32 GPIO, I2C (SDA/SCL), I2S (BCLK/LRC/DIN), servo **signal** wires, **VCC** on PCA9685/OLED | Servo **motor** power (red wire → PCA9685 **V+**), MAX98357A **Vin**, ESP32 **5V** input pad |
| **Current** | Milliamps per pin / tens of mA on a **VCC** rail | Up to **~1.5 A** when servos stall |

**VCC** on a breakout (3.3 V) = "power this chip's brain so it can read and drive ones and zeros." It is **not** the same net as the 5 V that spins a servo.

**5V** on the ESP32 board = "feed the module" — an onboard **LDO** drops that to 3.3 V so the chip's core and GPIO speak the right logic levels.

### What goes wrong if you mix them up

- **5 V on a GPIO / I2C / I2S line** — you're forcing a **"one" louder than the chip allows** (~3.3 V max on ESP32). Damage. See **Logic overvoltage** above.
- **Servo motor power from 3.3 V** — the line can't supply enough **current** to move metal; brownout or dead regulator. Signal wire at 3.3 V PWM is fine; **power** wire needs 5 V.

When you read `digitalWrite(pin, HIGH)` in firmware, picture **~3.3 V on that pin**. When you read a schematic's **3V3** net, picture **the rail that defines what a "one" looks like** for every chip tied to it.

---

## Two voltage domains (the idea)

Real boards rarely run everything at one voltage. You'll see:

- A **power rail** (often 5 V) for things that need muscle — motors, amplifiers
- A **logic rail** (3.3 V) where **ones and zeros live** — GPIO, I2C, I2S, chip **VCC**

They share GND (that's your **zero**). They do **not** share the same positive rail unless a regulator explicitly converts between them.

---

## In Tiny Engineer

This robot is a textbook example of **two domains on one USB cable**.

```mermaid
flowchart TB
  USB["USB 5V"]
  subgraph fiveV [5V domain]
    ESP5[ESP32 5V in]
    PCApwr[PCA9685 5V and V+]
    MAXvin[MAX98357A Vin]
    SERVOS[Servo motors]
  end
  subgraph threeV [3.3V logic domain]
    ESPcore[ESP32 GPIO and core]
    PCAlogic[PCA9685 VCC]
    OLED[OLED VCC]
  end
  USB --> fiveV
  ESP5 --> ESPcore
  ESPcore --> threeV
  PCApwr --> SERVOS
```

**5 V domain** — USB comes in through the main control board USB-C (advanced path: Adafruit 5993 — [wiring.md](../hardware/wiring.md#usb-connector-5993)) and feeds:
- ESP32 **5V** input (then an onboard LDO drops to 3.3 V for the chip)
- PCA9685 **5V** and **V+** (servo motor power)
- MAX98357A **Vin** (audio amp)

**3.3 V domain** — the ESP32's LDO generates the rail where **logic 1 = ~3.3 V** and **logic 0 = ~0 V**:
- ESP32 core and GPIO (your `HIGH` / `LOW` in code)
- PCA9685 **VCC** (chip logic + I2C — reads 0/1 on SDA/SCL)
- OLED **VCC** (display logic on the same I2C bus)

### The mistake that costs boards

The PCA9685 has **VCC** (3.3 V logic) and **V+** (5 V servo power). They must stay **separate**. Beginners jumper them because both say "power." Don't. You feed motor current into logic circuits or starve servos of voltage.

### Never power servos from 3.3 V

Five PowerHD HD-1370A servos at stall draw on the order of **1.3–1.6 A**. **SG90** (recommended) is larger and typically stalls harder. The ESP32's LDO is rated for hundreds of mA of *logic*. Plug servos into 3.3 V and you get brownout, reset, or a dead regulator. Servos get 5 V via PCA9685 **V+**; the signal wire is 3.3 V PWM from the driver — that's fine.

### Common GND

Every module — ESP32, PCA9685, OLED, amp, servos — ties GND to the same net. Power without shared GND is like deploying microservices that can't reach each other's network.

Full stall math and symptom tables: [power.md](../hardware/power.md).

---

**Next:** [Microcontrollers and ESP32](02-microcontrollers-and-esp32.md)

**Reference:** [hardware/power.md](../hardware/power.md) · [hardware/main-control-board.md](../hardware/main-control-board.md) · [hardware/wiring.md](../hardware/wiring.md)

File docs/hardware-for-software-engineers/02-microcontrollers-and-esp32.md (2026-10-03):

# Microcontrollers and ESP32

Your laptop runs Linux, Chrome, and seventeen Slack notifications. A microcontroller runs *one program*, forever, with no OS you recognize. That gap — between "real computer" and "chip that drives GPIO" — is where most software engineers stall. This chapter closes it. Tiny Engineer uses an **ESP32-C3** as its instance; the ideas apply to Arduino, STM32, and most hobby boards.

---

## MCU vs SBC vs your laptop

| | Microcontroller (MCU) | Single-board computer (SBC) | Laptop |
| --- | --- | --- | --- |
| Examples | ESP32, Arduino, STM32 | Raspberry Pi, BeagleBone | What you're reading this on |
| OS | Bare-metal or RTOS; often "Arduino" | Full Linux | Full OS |
| Boot time | Milliseconds | Seconds | Minutes if updates pending |
| GPIO pins | Yes, direct | Yes, but often through OS layers | Basically no |
| Real-time I/O | Designed for it | Possible, awkward | Not the point |
| Power | Milliwatts to low watts | Watts | Tens of watts |

Tiny Engineer needs Wi-Fi, five servos, a display, and audio on a desk robot budget. An MCU with built-in radio fits. A Pi would work but adds OS overhead, boot time, and power for no gain here.

---

## What firmware is

**Firmware** is the program stored in flash on the chip. It runs on boot. There's no `git pull` on the device — you **build** on your computer and **upload** (flash) the binary over USB.

> **If you've written backend code…** Flashing firmware is deploying a single static binary to a device with no package manager. Serial monitor is `stdout`. There's no SSH — you re-flash or use HTTP once Wi-Fi works.

**Flash** = non-volatile storage (survives power-off). Holds your program and, on this project, LittleFS files (WAV sounds).

**RAM** = working memory. Much smaller than flash. Gone on reboot.

---

## GPIO — the hardware API

**GPIO** (General Purpose Input/Output) pins are wires the firmware controls or reads. On the wire that is literally **zeros and ones** as voltages (see [Ch. 01](01-electricity-and-units.md)):

- **Output HIGH / 1** ≈ 3.3 V on that pin (on ESP32)
- **Output LOW / 0** ≈ 0 V (GND)
- **Input** — read whether the other side is holding the line high or low

Blink an LED? Firmware toggles one pin between 0 and 1. Same idea scales up: **communication protocols are patterns of zeros and ones on one or more pins over time** — serial (UART), I2C, SPI, I2S, even USB on this chip. Libraries hide the bit timing; underneath it's still GPIO-level signaling.

You don't get unlimited pins. Each pin might be reserved for flash, USB, or boot strapping. Scarcity is real — see [pinout.md](../hardware/pinout.md) for the full map.

---

## Boot, reset, and upload

**RESET** — reboots the chip (like killing and restarting a process).

**BOOT** — strapping pin; hold during reset to enter serial upload mode if auto-reset fails.

**Upload** — PlatformIO sends firmware over USB. On ESP32-C3, that's **native USB** on specific GPIO pins (not a separate USB-UART chip).

If upload fails: try another cable (data, not charge-only), another port, hold BOOT, check drivers. Details in [flash.md](../flash.md).

---

## What "Arduino on ESP32" means

This project uses **PlatformIO** with the **Arduino framework** for ESP32. You get `setup()` / `loop()`, familiar libraries (`Wire` for I2C, etc.), and Espressif's Wi-Fi stack underneath.

You're not writing bare-metal RISC-V assembly. You're writing C++ that compiles to a binary the chip runs directly. `platformio.ini` picks the board target and libraries.

---

## ESP32 family (just enough context)

Espressif makes many ESP32 variants. Tiny Engineer uses **ESP32-C3**:

- **RISC-V** single-core (not the older dual-core Xtensa ESP32)
- **Wi-Fi 2.4 GHz only** — no 5 GHz; your router must expose 2.4 GHz for setup
- **BLE** exists on the silicon; this project's firmware doesn't use it
- Native **USB** — no external CP2102 required when wired correctly

---

## In Tiny Engineer

### The board: Waveshare ESP32-C3-Zero

Not a generic breadboard devkit. It's a compact module with castellated edges, a ceramic antenna, and an onboard RGB LED.

**PlatformIO naming trap:** `board = esp32-c3-devkitm-1` in `platformio.ini` is a **build target name**, not the physical board in your hand. The physical board is the C3-Zero. Same chip, different pin breakout — the project's [pinout.md](../hardware/pinout.md) and [components.md](../hardware/components.md) describe *this* board.

### What the ESP32 does here

| Job | How |
| --- | --- |
| Wi-Fi + HTTP API | Agent integration, web UI, `/anim`, `/test/*` |
| I2C master | Talks to PCA9685 (servos) and OLED (display) |
| I2S master | Streams audio samples to MAX98357A |
| Status RGB | Onboard WS2812 on GPIO10 — boot green, anim white, error red |
| "Sensor" | On-die CPU temperature in `/health` — that's it, no IMU |

### Pins you'll hear about (conceptual)

The firmware dedicates most exposed GPIOs. Rough mental map:

- **GP0 / GP1** — I2C (SDA / SCL) to PCA9685 and OLED
- **GP2–GP4** — I2S (BCLK, LRC, DIN) to audio amp
- **GP9** — BOOT button
- **GP10** — onboard RGB LED
- **GP18 / GP19** — native USB D− / D+ (main control board USB-C when assembled; advanced path: Adafruit 5993 — [wiring.md](../hardware/wiring.md))

Many other GPIOs are used internally for flash and aren't available. Don't reassign USB pins if you flash over that cable.

Full allocation: [pinout.md](../hardware/pinout.md).

### USB: onboard vs robot connector

The C3-Zero has a USB-C port on the module. **When the robot is assembled**, flash and serial go through the **main control board USB-C**, which reaches GPIO18/19. One cable on the robot for power and programming. The advanced breakout path uses an Adafruit 5993 on those same pins — [wiring.md](../hardware/wiring.md).

### The RGB LED is your boot log

Before Wi-Fi works, the LED tells you state: dim green while booting; a fatal init failure hangs and blinks red (1 = PCA9685 missing, 2 = I2S failed). It's the hardware equivalent of a health-check endpoint you can see without serial. Blink table: [hardware/testing.md](../hardware/testing.md#boot-failure-blink-codes).

### Ceramic antenna — don't bury it

Wi-Fi is how coding agents talk to the robot. The C3-Zero uses a **ceramic antenna** on the board. Metal or thick plastic pressed against it kills range. When you design or assemble the shell, leave a keep-out zone. More in [Ch. 06](06-3d-printing-and-mechanical-build.md).

### Flash workflow

Build, upload, monitor — copy-paste lives in [flash.md](../flash.md). This chapter stops at *what* the chip is; that page is *how* to deploy.

---

**Next:** [Wiring craft and schematics](03-wiring-craft-and-schematics.md)

**Reference:** [hardware/components.md](../hardware/components.md) · [hardware/pinout.md](../hardware/pinout.md) · [flash.md](../flash.md)

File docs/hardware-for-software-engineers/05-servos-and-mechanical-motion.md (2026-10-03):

# Servos and mechanical motion

**Position servos** are everywhere in hobby robotics — small actuators that go to an angle and hold. They're not stepper motors, not DC gearmotors. Understanding them saves you from stripped gears and firmware angles that mean nothing physically. Tiny Engineer has **five** of them; the mechanics chapter applies to any servo-driven joint.

---

## What a hobby servo is

A **position servo** (hobby analog micro servos in this build — [which servo](../3d/parametric-design.md)) contains:

- Motor
- Gear train
- Potentiometer (position feedback)
- Control board that compares commanded pulse width vs actual angle

You command an **angle** (via pulse width). The servo tries to reach it and **holds** there — even against light load.

**Not** continuous rotation — it stops at mechanical limits (~130° usable on some units such as PowerHD HD-1370A, marketed sometimes as 180°).

**Three wires:**
| Wire | Role |
| --- | --- |
| Signal (SIG) | PWM in — angle command |
| +5 V (red) | Motor power |
| GND (brown/black) | Common ground |

Power and signal are separate. The signal wire is low current; the power wire carries motor current.

PWM here means a timed HIGH pulse on the signal wire — how long that HIGH lasts is the angle. Full protocol picture (and why a PCA9685 does it): [Ch. 04 — Buses and protocols](04-buses-and-protocols.md#pwm--how-long-high-lasts-is-the-angle).

---

## PWM as angle — recap

Short version (details in [Ch. 04](04-buses-and-protocols.md#pwm--how-long-high-lasts-is-the-angle)): ~50 Hz frame, pulse width sets target:

- ~1500 µs ≈ center / neutral
- Shorter pulse → one direction
- Longer pulse → other direction

Firmware maps 0–180° to **800–2200 µs** on this project. That's the *electrical* range. The *mechanical* range in the assembled robot is narrower — see below.

---

## Horns, splines, and alignment

On this robot (and most 3D-printed hobby builds) the **servo body sits in a printed pocket** — screws or a tight fit, not a metal bracket. The printed part *is* the mount. The moving piece is whatever is on the **output shaft**.

**Spline** — toothed shaft on the servo. **Horn** — the small plastic arm (or a printed piece that mates the same teeth) that locks onto that spline. Teeth only line up in discrete steps — one tooth off and the rest pose is wrong.

**Typical order:**
1. Seat the servo in the printed pocket (don't force — reprint or ream if it's a press-fit from hell)
2. Power to **center** (firmware boot centers slowly on purpose)
3. Press the horn / printed lever onto the spline at the **neutral pose** for that joint (hand down, head looking at the laptop, etc.)
4. Horn screw from the servo bag — snug, not stripped

The printed pocket holds the **case**. The horn (or printed horn-shaped part) transfers **rotation** into the next printed piece. Misalign the spline and the hand hits the desk at "90°" in firmware.

**Off-by-one spline** — one tooth wrong → rest pose crooked → you clamp in software until you hit a printed stop and gears slip.

> **If you've written backend code…** Horn alignment is the zero offset. Wrong offset corrupts everything downstream. Software clamps don't fix a printed stop.

---

## Mechanical limits vs firmware limits

Two layers of limits:

| Layer | What limits | Where defined |
| --- | --- | --- |
| **Electrical** | 800–2200 µs pulse | Firmware constants |
| **Mechanical** | Horn hits shell, linkage binds, servo stalls | Your assembly |
| **Safe software** | Clamped angles per joint | `SERVO_SPECS` in firmware |

Always respect **safe ranges** for the assembled robot — [robot-movement.md](../robot-movement.md). `POST /test/movement` sweeps each joint inside its saved min/max; don't slam full electrical range into a built shell.

**Tune after assembly:** if a hand hits the desk at 135°, lower that joint’s max in the setup AP wizard (saved to NVS) or reorient the horn — don't "just command less" in one script and forget. Stock defaults live in `SERVO_SPECS`; assembled motion uses the saved min/max.

---

## Backlash, binding, stall

**Backlash** — gear slack; small commanded moves may not visibly move until slack is taken up. Normal at micro scale.

**Binding** — linkage too tight, screw into moving path, printed hole too small. Servo buzzes, draws stall current, gets hot.

**Stall** — servo commanded past mechanical stop. High current (~260–320 mA per servo at stall). Five servos stalling together browns out the board. Hear buzzing? Stop commanding into the stop.

---

## The Tiny Engineer servo stack

End-to-end path from HTTP to motion:

```mermaid
flowchart LR
  HTTP["POST /test/servo"]
  FW["Firmware angle clamp"]
  I2C["I2C to PCA9685 0x40"]
  PWM["50 Hz PWM ch 0-4"]
  SRV["analog micro servos"]
  HTTP --> FW --> I2C --> PWM --> SRV
```

1. You hit `/test/servo` or an animation (see [api.md](../api.md))
2. Firmware clamps angle to `SERVO_SPECS` safe range for that joint
3. I2C write to PCA9685 at address `0x40`
4. Chip outputs 50 Hz PWM on channel 0–4
5. Servo moves

**Channel → joint mapping** (names only — angles in [robot-movement.md](../robot-movement.md)):

| Channel | Joint | Motion |
| --- | --- | --- |
| 0 | Head | Pitch (nod) |
| 1 | Neck | Yaw (turn) |
| 2 | Left hand | Up/down |
| 3 | Right hand | Up/down |
| 4 | Body | Torso twist |

### Left vs right hand — inverted scale

The left and right hand servos mirror each other physically. Firmware uses **opposite angle mapping**: on the left, higher angle = up; on the right, higher angle = down. Rest pose for "typing" uses left at max, right at min.

Symmetric code, asymmetric hardware — normal in robots.

### Boot centering — slow on purpose

On boot, servos move to center at **35°/s** (`SERVO_BOOT_SPEED_DEG_S`), not full speed. Sudden jumps on power-up strip gears and scare you. Live motion can be faster — see [servos.md](../hardware/servos.md).

### PCA9685 is required

No PCA9685 at `0x40` → init fails, red LED, hang. Unlike the OLED. Plan bring-up accordingly.

---

## Safe-range checks during assembly

Do this after wire/flash, on the desk, and while centering joints ([assembly.md](../3d/assembly.md)) — before final screws jam a horn against plastic:

1. After wire/flash, keep electronics on the desk; confirm serial shows PCA9685 OK
2. Command one joint via setup AP **Move all to 90°**, web UI, or `/test/servo`
3. Seat each printed part on a centered shaft; sweep the **safe range** slowly — watch for binding
4. Unplug between awkward joins; reconnect channels when the guide says so

Software can clamp angles; it can't un-strip a gear. Don't wait until the chest is closed to discover a stall.

---

**Next:** [3D printing and mechanical build](06-3d-printing-and-mechanical-build.md)

**Reference:** [robot-movement.md](../robot-movement.md) · [hardware/servos.md](../hardware/servos.md) · [api.md](../api.md)

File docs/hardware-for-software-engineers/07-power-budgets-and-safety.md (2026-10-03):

# Power budgets and safety

Software crashes give you a stack trace. Power problems give you "it worked until I ran an animation" and random reboots. This chapter is capacity planning for electrons — any design that pairs a microcontroller with motors or audio will hit the same wall. Tiny Engineer's five servos make the math honest.

---

## Why the supply rating matters

A USB charger label says **5 V / 2 A**. That's a promise of voltage and *maximum* current the source can sustain.

Every load draws what it needs (not what the label says). **Current adds in parallel:**

- ESP32 + Wi-Fi TX — tens to hundreds of mA peaks
- OLED + PCA9685 logic — tens of mA
- MAX98357A + speaker — peaks on loud WAV
- **Five servos** — **~1.3–1.6 A** if several stall together (PowerHD HD-1370A datasheet). **SG90** (recommended) is larger and typically stalls harder — still **5 V / ≥ 2 A**, with extra margin if several move during audio.

A **1 A phone charger** is not enough. Recommendation: **5 V / ≥ 2 A**, with margin if servos move during audio.

---

## Stall current — worst-case load test

A **stall** is when the motor tries to move but can't — horn against stop, binding linkage, desk collision.

Per PowerHD HD-1370A datasheet (approximate):

| Condition | Per servo | × 5 servos |
| --- | --- | --- |
| Stall @ ~4.8 V | ~260 mA | **~1.3 A** |
| Stall @ ~6.0 V | ~320 mA | **~1.6 A** |

Robot rail is ~5 V — expect something in between if multiple HD-1370A servos stall at once. **SG90** (recommended) typically stalls harder; still use **5 V / ≥ 2 A**, with extra margin if several move during audio.

That's **before** Wi-Fi, display, and audio peaks.

> **If you've written backend code…** Stall current is your load test at 100× traffic. The supply must survive it or the whole service restarts (brownout).

---

## Tiny Engineer power budget story

Walk through a bad scenario:

1. Robot on a **1.5 A** USB port (5993 breakout advertises up to ~1.5 A via CC resistors — actual delivery depends on the charger)
2. Animation commands three servos at once
3. Wi-Fi transmits HTTP response
4. WAV plays through MAX98357A
5. Rail sags below ESP32 brownout threshold
6. **Reset** — looks like firmware bug; serial shows boot loop

**Symptom map:**

| Symptom | Often actually |
| --- | --- |
| Reset when servos start | Insufficient 5 V current |
| Servo jitter / weak torque | Sagging rail or thin power wires |
| OLED blank / glitch during motion | Power or I2C glitch from sag |
| I2C NACK after motion | Brownout side effect, not bad address |
| Audio crackle on loud sounds | Rail dip under combined load |

Full numbers and architecture: [power.md](../hardware/power.md).

---

## VCC vs V+ (again, because it burns boards)

On PCA9685:

| Pin | Voltage | Powers |
| --- | --- | --- |
| **VCC** | 3.3 V | Chip logic, I2C |
| **V+** | 5 V | Servo motor rail |

Jumpering them = wrong domain crossover. See [Ch. 01](01-electricity-and-units.md).

**Never** power servos from ESP32 **3V3** — LDO is for logic, not ~1.5 A of motors.

---

## USB-C — what it does and doesn't do

The default robot connector is the main control board USB-C ([power.md](../hardware/power.md)). This list is the advanced Adafruit 5993 — [wiring.md](../hardware/wiring.md#usb-connector-5993).

**Does:**
- Bring USB-C connector to your wiring
- Pass **5 V** and **GND**
- Route **D+ / D−** to ESP32 for flash/serial
- Advertise ~1.5 A sink via CC resistors

**Does not:**
- Convert USB-PD 9/12/20 V down to 5 V
- Create current — only passes what the upstream charger provides

Weak laptop port or thin cable → voltage drop → mystery failures. Use a known-good **2 A** brick and a **data-capable** cable.

---

## Voltage drop on wires

Thin/long power wires have resistance. At 1.5 A, even small R means measurable voltage lost *before* the load.

**Mitigation:** shorter, thicker runs for 5 V servo power; star GND at the board USB-C (or at the 5993 on the advanced path); don't daisy-chain power through a single Dupont jumper for all servos.

---

## Brownout

**Brownout** — supply voltage drops below what the MCU needs. ESP32 resets or behaves erratically. No graceful shutdown.

Feels like:
- Random reboot mid-animation
- "It works on USB from laptop but not from power bank"
- Worse when battery-powered USB packs sag

Fix the supply, not the code (usually).

---

## First power-up mindset

Before applying power:

1. **Visual inspect** — no obvious shorts, VCC/V+ not jumpered wrong
2. **Continuity** — multimeter beep: GND common across modules (power off!)
3. **Resistance** — no dead short between 5 V and GND (power off!)
4. **Strong supply** — bench 5 V / 2 A preferred over unknown port
5. **Servos unloaded** — horns free to move, not wedged against stops
6. **One subsystem at a time** if debugging — see [Ch. 08](08-tools-debugging-and-embedded-workflow.md)

Assembly checks: [main-control-board.md](../hardware/main-control-board.md). Advanced harness: [wiring.md](../hardware/wiring.md).

---

## ESD and handling

Static discharge can kill sensitive chips. Touch grounded metal before handling ESP32. Don't slide modules on carpet. For a hobby desk build, basic awareness beats paranoia — but don't treat the C3-Zero like a rug skateboard.

---

## In Tiny Engineer — domain diagram

```mermaid
flowchart TB
  USB["USB 5V"]
  subgraph fiveV [5V domain]
    ESP5[ESP32 5V in]
    PCApwr[PCA9685 5V and V+]
    MAXvin[MAX98357A Vin]
    SERVOS[Servo motors]
  end
  subgraph threeV [3.3V logic domain]
    ESPcore[ESP32 GPIO and core]
    PCAlogic[PCA9685 VCC]
    OLED[OLED VCC]
  end
  USB --> fiveV
  ESP5 --> ESPcore
  ESPcore --> threeV
  PCApwr --> SERVOS
```

Strong 5 V bring-up on the desk after [connecting the main control board](../hardware/main-control-board.md) and [flash](../flash.md) ([getting-started](../getting-started.md)) **before** closing the chest. Debugging power inside a sealed shell is dark work. Advanced harness: [wiring.md](../hardware/wiring.md).

---

**Next:** [Tools, debugging, and embedded workflow](08-tools-debugging-and-embedded-workflow.md)

**Reference:** [hardware/power.md](../hardware/power.md) · [hardware/main-control-board.md](../hardware/main-control-board.md) · [hardware/wiring.md](../hardware/wiring.md)

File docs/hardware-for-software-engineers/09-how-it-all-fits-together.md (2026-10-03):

# How it all fits together

You've read the pieces. This chapter closes the loop on the guide's goal — **from software-only to hardware-capable** — then hands you to the build checklist. Tiny Engineer is the capstone: one system where electricity, firmware, buses, print, and motion connect. The vocabulary you picked up travels with you to the next board.

**Expect medium difficulty overall** — not an entry-level blinky kit, but a fair first hardware build for a software engineer who read the guide and validates electronics on the desk (connect + flash) before closing the chest. The default build is the main control board. Harness examples in this guide are the advanced path — [wiring.md](../hardware/wiring.md). Hardest areas for most SWEs: wiring density on that advanced path, servo mechanics, power under load. Easiest: REST and Wi-Fi once that smoke check is solid.

---

## Three phases

```mermaid
flowchart TB
  subgraph learn [Learn phase]
    A[Electricity basics]
    B[MCU + buses]
    C[Print + mechanics]
  end

  subgraph build [Build phase]
    D[Print parts]
    E[Wire_flash_desk_smoke]
    F[Assemble]
  end

  subgraph run [Run phase]
    H[Wi-Fi + web UI]
    I[REST API + agent hooks]
  end

  learn --> build --> run
  D --> E --> F
```

**Learn** — this guide. Enough to not fry boards.

**Build** — [getting-started.md](../getting-started.md). Checklist: shop, print, connect, flash, assemble, wizard, prove.

**Run** — Wi-Fi, `/anim`, Cursor hooks or your own integration.

You can overlap phases (print while reading). Don't skip **desk smoke** (serial, PCA9685, one servo) before seating the board in the chest.

---

## The whole robot — one diagram

```mermaid
flowchart TB
  Agent["AI agent / curl / web UI"]
  Agent -->|HTTP Wi-Fi 2.4GHz| ESP["ESP32-C3-Zero"]

  subgraph power [Power from board USB-C]
    V5[5V rail]
    V33[3.3V logic via LDO]
  end

  ESP --> V5
  V5 --> V33

  ESP -->|I2C GP0/1| PCA["PCA9685 0x40"]
  ESP -->|I2C GP0/1| OLED["OLED 0x3C"]
  ESP -->|I2S GP2-4| AMP["MAX98357A"]
  AMP --> SPK[Speaker]

  V33 --> PCA
  V33 --> OLED
  V5 --> AMP
  PCA -->|V+ 5V PWM| SRV["5 analog micro servos"]

  PCA --> SRV

  subgraph mech [Printed mechanics Fusion to 3mf]
    BODY[Head Neck Hands Body]
  end

  SRV --> BODY
  ESP -.->|antenna keep-out| BODY
```

**Control plane:** Wi-Fi HTTP from your LAN.

**Data paths:** I2C for servos (via PCA9685) and display; I2S for audio.

**Power plane:** One 5 V in; 3.3 V logic derived; servos on 5 V motor rail.

**Mechanical plane:** Fusion CAD → printed parts → servos → pose.

---

## Subsystem → chapter map

| Subsystem | Learn in | Operate with |
| --- | --- | --- |
| Volts, amps, GND, two domains | Ch. 01, 07 | [power.md](../hardware/power.md) |
| ESP32-C3, GPIO, USB, antenna | Ch. 02 | [pinout.md](../hardware/pinout.md) |
| Wires, schematic reading | Ch. 03 | [main-control-board.md](../hardware/main-control-board.md). Advanced: [wiring.md](../hardware/wiring.md), [diagram](../wiring/Tiny%20Engineer.drawio.png) |
| I2C, I2S, PWM | Ch. 04 | [interfaces.md](../hardware/interfaces.md) |
| Servos, horns, joints | Ch. 05 | [robot-movement.md](../robot-movement.md), [servos.md](../hardware/servos.md) |
| Print, PLA/PETG, Fusion | Ch. 06 | [3d_models/README.md](../../3d_models/README.md) |
| Supply sizing, brownout | Ch. 07 | [power.md](../hardware/power.md) |
| pio, serial, bisect debug | Ch. 08 | [testing.md](../hardware/testing.md) |
| HTTP API, agents | — (after hardware) | [api.md](../api.md), [integration.md](../integration.md), [hooks.md](../hooks.md) |

---

## Recommended build strategy (software brain edition)

Follow the checklist in [getting-started.md](../getting-started.md). Summary:

1. **Shop** → [shopping.md](../shopping.md) (main control board)
2. **Print or order** (can overlap with learning) → [3d_models](../../3d_models/README.md)
3. **Connect** + **flash** on the desk → [main-control-board.md](../hardware/main-control-board.md), then [flash.md](../flash.md). Extra modules: [wiring.md](../hardware/wiring.md)
4. **Assemble** (one run: Head/Hat, centering, joins) → [assembly.md](../3d/assembly.md) §§1–19
5. **Setup wizard** → assembly §20
6. **Prove** (`/health`, `ring`) → [getting-started §7](../getting-started.md#7-prove-it)
7. **Agent hooks** → [hooks.md](../hooks.md) / [integration.md](../integration.md)

**Desk smoke is first:** with boards still on the desk, confirm serial boot, PCA9685 OK, and one servo via `/test/servo` or setup AP **Move all to 90°**. Then one mechanical run. Do not finish the wizard until §20.

**Temptation to avoid:** printing everything beautifully before verifying electronics. Pretty plastic won't fix a swapped SDA/SCL.

---

## Confidence milestones

Check these off — order matches the checklist:

| # | Milestone | When | How you know |
| --- | --- | --- | --- |
| 1 | **Continuity sanity** | connect | No short 5V–GND; GND common (meter, power off) |
| 2 | **Serial boot** | flash | `pio device monitor` shows boot log, dim green LED |
| 3 | **PCA9685 detected** | flash | Serial OK; missing = 1 red blink, hang ([blink codes](../hardware/testing.md#boot-failure-blink-codes)) |
| 4 | **One servo / 90°** | flash | Setup AP **Move all to 90°** or `/test/servo` moves a channel |
| 5 | **Joints in safe range** | assembly §§1–19 | Each joint centered and joined; no stall buzz |
| 6 | **Board seated** | late assembly | Same electronics checks still pass after mounting in the chest |
| 7 | **Wi-Fi stable** | after §20 wizard | `/health` over `tiny-engineer.local` or OLED IP |
| 8 | **Audio + full anim** | prove it | e.g. `ring` — motion + sound (if silent → `uploadfs`) |
| 9 | **Agent** | optional | Cursor hook or script triggers `/anim` |

Stuck on a milestone? Back one step, read [Ch. 08](08-tools-debugging-and-embedded-workflow.md) and [testing.md](../hardware/testing.md).

---

## What I'd tell any software engineer starting hardware

Not specific to day one on Tiny Engineer — things that stayed true across projects:

1. **Two voltages, one GND** — not optional mental model
2. **PCA9685 isn't optional** — plan I2C before servos
3. **Power is a feature** — 2 A supply saves hours of "random reboot" debugging
4. **Horns are calibration** — software clamps can't fix physical collision
5. **Wire + flash on the desk first, then one mechanical run** — smoke before closing the chest
6. **The docs split on purpose** — this guide for *why*, getting-started for *do*, hardware/ for *lookup*

The meta-lesson: hardware rewards the same curiosity that got you into software, but feedback is louder — smoke, buzz, heat. That's part of the fun.

---

## Handoff — go build

You're done with concepts when the milestones make sense and you know which doc to open for pin numbers.

**Operational checklist:** [getting-started.md](../getting-started.md)

**Shop → print → wire → flash → assemble → wizard → prove → hooks.**

If you're mostly a software person: good. The bar isn't an EE degree — it's curiosity and willingness to probe a wire. In a world where AI spits out code in seconds, there's a particular joy in something on your desk that moves because *you* closed the loop from schematic to screw. Tiny Engineer is a fun capstone — but the bridge you built here works for the next project too.

---

**Next:** none — start building, or re-read any chapter from the [README](README.md).

**Reference:** [getting-started.md](../getting-started.md) · [hardware/README.md](../hardware/README.md) · [README.md](README.md)

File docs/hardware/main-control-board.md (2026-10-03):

# Main control board

Default connect guide. Same firmware and pins as the advanced breakout harness. Cart: [shopping.md](../shopping.md).

The board is **open source** ([CERN-OHL-S](../../3d_models/LICENSE)). KiCad sources: [`hardware/boards/main-control-board/`](../../hardware/boards/main-control-board/). Export Gerbers and order from any fab yourself — step-by-step (JLCPCB example): [order-main-control-board.md](order-main-control-board.md). The [interest check](https://github.com/jamro/tiny-engineer/discussions/50) is optional — a community batch for easier / cheaper buys, not a gate to use the design.

On the board: PCA9685, MAX98357A, USB-C (power + data). Still plug in: ESP32-C3-Zero, OLED, five servos, speaker. Electrical detail for contributors: the board README in that folder.

Seat the PCB in the printed `Desk` during [assembly §12–13](../3d/assembly.md#12-electronics-inside-the-desk). This page is the electrical plug-in procedure.

## Connect

**Power / flash / serial** use the board **USB-C** (data cable). Do not also wire a separate Adafruit 5993.

1. **ESP32-C3-Zero** — Plug into the top headers. Module pins pass through the dedicated cut in the desk top (see assembly). Orient using the **USB** marking on the PCB silkscreen so the module matches the cut and USB side.
2. **OLED** — Plug into the male header labeled **OLED**.
3. **Servos** — Plug into the labeled servo sockets. Match socket orientation (signal / 5 V / GND as labeled). Which joint → which channel: [pinout.md](pinout.md#pca9685-channels-not-esp32-gpio).
4. **Speaker** — Use **one** method only, never both:
   - **Connector:** stock Adafruit Mini Oval — plug as labeled. A non-Adafruit / alternate speaker may work; check polarity. If phase is wrong or the plug pinout differs, swap wires in the connector.
   - **Solder pads:** solder the speaker leads to the dedicated speaker pads on the board.
   - **Never** connect both the connector and the solder pads at the same time.

## Pre-power checks

- Speaker: connector **or** pads, not both. **SPK− is not ground.**
- Servo plugs oriented to the labels; leave channels unplugged until centering if you prefer.
- ESP32 seated in the correct orientation (PCB USB mark).
- Supply **5 V / ≥2 A** on the board USB-C.

Supply and speaker rules: [getting-started Safety](../getting-started.md#safety). Power architecture: [power.md](power.md).

## Next

[Flash](../flash.md) on the desk, then continue [getting-started](../getting-started.md) → assemble.

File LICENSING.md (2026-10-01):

# Licensing

This repository contains both software and hardware design files. They are licensed separately.

## Software — MIT License

The following are licensed under the [MIT License](LICENSE):

| Path | Contents |
| --- | --- |
| `src/`, `include/`, `lib/`, `test/` | Firmware |
| `packages/`, `scripts/`, `package.json` | Integrations and tooling |
| `data/`, `assets/` | Firmware filesystem assets |
| `docs/` | Documentation (including wiring diagrams and hardware guides) |
| `.cursor/` | Cursor hook configuration |
| `platformio.ini`, `partitions.csv` | Build configuration |
| All other repository files | Unless explicitly listed under hardware below |

## Hardware designs — CERN-OHL-S-2.0

Mechanical CAD, printable manufacturing outputs, and PCB sources are licensed under the [CERN Open Hardware Licence Version 2 — Strongly Reciprocal (CERN-OHL-S-2.0)](3d_models/LICENSE):

| Path | Contents |
| --- | --- |
| `3d_models/cad/` | Source CAD (`.f3d`) |
| `3d_models/parts/` | Printable part exports (`.3mf`) |
| `mods/*/3d_models/cad/`, `mods/*/3d_models/parts/` | Mod CAD and manufacturing exports |
| `hardware/boards/` | KiCad PCB projects |

Commercial use of these hardware designs is allowed. If you modify and distribute Products based on these designs, the reciprocal provisions of CERN-OHL-S-2.0 require that you make the corresponding Complete Source available under the same license. See [3d_models/LICENSE](3d_models/LICENSE), [3d_models/NOTICE](3d_models/NOTICE), [hardware/LICENSE](hardware/LICENSE), and [hardware/NOTICE](hardware/NOTICE) for copyright, warranty disclaimer, and Source Location details.

Documentation in `3d_models/README.md`, `mods/README.md`, and `hardware/README.md` is software documentation and remains under the MIT License. Other files beside a mod’s `3d_models/` folder are MIT as well.

### Source Location

Canonical mechanical design source:

`https://github.com/jamro/tiny-engineer/tree/main/3d_models`

Optional mod CAD and exports use that mod’s `3d_models` tree (for example `https://github.com/jamro/tiny-engineer/tree/main/mods/halloween/3d_models`).

Canonical PCB design source:

`https://github.com/jamro/tiny-engineer/tree/main/hardware`

When distributing a specific revision, link to the corresponding tagged release or commit (for example, `https://github.com/jamro/tiny-engineer/tree/v0.1.0/3d_models`).

## Trademarks

The **Tiny Engineer** name and logo are **not** licensed under either MIT or CERN-OHL-S-2.0. See [TRADEMARK.md](TRADEMARK.md).

## Machine-readable license mapping

Per-path SPDX annotations are in [REUSE.toml](REUSE.toml).

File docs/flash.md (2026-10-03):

# Flash firmware

Flash **after connect, before assembly**. Overview order: [getting-started.md](getting-started.md). Centering (Move all to 90°) happens on the desk with the main control board; do not finish the Wi-Fi wizard until [assembly.md §20](3d/assembly.md#20-setup-wizard-and-first-boot-on-wi-fi).

Firmware is Arduino on [PlatformIO](https://platformio.org/) ([pioarduino](https://github.com/pioarduino/platform-espressif32) / Arduino-ESP32 3.x). Board and baud live in `platformio.ini`.

Physical module is a **Waveshare ESP32-C3-Zero**. PlatformIO `board = esp32-c3-devkitm-1` is a **build target name**, not a different board.

## Install and connect

1. Install [PlatformIO Core](https://docs.platformio.org/en/latest/core/installation.html) (or the PlatformIO IDE extension).
2. Use a USB-C **data** cable. Charge-only cables fail upload and serial.
3. Plug the data cable into the **main control board USB-C** once the ESP32 is seated on its headers. Advanced breakout build: use the Adafruit 5993, or the C3-Zero onboard USB-C before that breakout is wired — [hardware/wiring.md](hardware/wiring.md).

## Build, upload, serial

From the project root:

```bash
pio run                 # build
pio run -t upload       # flash firmware + LittleFS
pio device monitor      # serial (115200)
```

After firmware upload, a post-script also uploads **LittleFS** ([`scripts/upload_fs_after_upload.py`](../scripts/upload_fs_after_upload.py)) so WAV assets (`welcome`, `bell`, and friends) land on the board. If animations move but stay silent, run `pio run -t uploadfs` once.

## Audio mods

Leave `custom_audio_mod` empty in [`platformio.ini`](../platformio.ini) for the stock clips in [`assets/`](../assets/). Set it to a mod folder name to overlay that mod's WAVs, then flash firmware and the filesystem together:

```ini
custom_audio_mod = halloween
```

```bash
pio run -t upload
```

The pack step copies `assets/*.wav`, then overwrites any matching file in `mods/<name>/assets/`. A clip the mod does not ship stays the stock file. `welcome`, `attention`, `error`, `abort`, and `dead` replacements need a sibling `.cue` (`key=ms` phrase marks). `bell` does not. Details: [`mods/README.md`](../mods/README.md).

The `spiffs` partition starts at `0x220000` and is about 1.81 MB, so a longer replacement set can fit. NVS stays at `0x9000`, so saved settings stay. An image flashed at the old `0x270000` offset will not mount. Use `pio run -t upload` (app + filesystem), not a firmware-only flash, after pulling this layout.

Several serial ports:

```bash
pio device list
pio run -t upload --upload-port <PORT>
pio device monitor --port <PORT>
```

`<PORT>` is the name `pio device list` prints for the board, and it is
platform-specific: `COM4` on Windows, `/dev/cu.usbmodemXXXX` or
`/dev/cu.usbserial-XXXX` on macOS, `/dev/ttyACM0` or `/dev/ttyUSB0` on Linux.
Pick the entry whose hardware ID shows Espressif's `VID:PID=303A:1001` (the
ESP32-C3's native USB) or your board's USB-serial bridge — `pio device list`
also lists Bluetooth serial ports, which are not the board.

## Done when

Firmware + LittleFS uploaded, and:

- Serial shows a normal boot (`TINY ENGINEER` … PCA9685 found … no hang)
- Onboard RGB is **dim green** during init (not a repeating red blink)
- One servo moves: join setup AP `TinyEngineer-XXXX`, open `http://192.168.4.1/config`, press **Move all to 90°** (or `POST /test/servo`)

Fatal init hangs and blinks the RGB **red**. Count flashes before the long gap:

| Blinks | Meaning |
| --- | --- |
| 1 | PCA9685 not found on I2C `0x40` — wiring / address |
| 2 | MAX98357A / I2S init failed |

Details: [hardware/testing.md — boot-failure blink codes](hardware/testing.md#boot-failure-blink-codes).

**Stop here.** Do not complete the setup wizard (home Wi-Fi, ranges, OLED, LED, speaker) until the robot is assembled — [assembly.md §20](3d/assembly.md#20-setup-wizard-and-first-boot-on-wi-fi). Then return to [getting-started](getting-started.md) and assemble.

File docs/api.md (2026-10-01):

# HTTP API

JSON HTTP server on the ESP32-C3. Source: [`src/http/http_server.cpp`](../src/http/http_server.cpp) and handlers under [`src/http/`](../src/http/), test routes in [`src/http/test_handlers.cpp`](../src/http/test_handlers.cpp).

Listens on **port 80** after STA Wi-Fi connects, or during setup AP mode at `http://192.168.4.1/`. Base URL is the board IP (OLED / serial) or `http://tiny-engineer.local` (mDNS, 2.4 GHz only).

Optional auth: when an `access_token` is configured in settings, all JSON API routes require `Authorization: Bearer <token>`. Empty token (default) means no auth. `GET /auth` is always public and reports whether auth is required. Missing/wrong token → **401** `{"ok":false,"error":"unauthorized"}`. HTML panel routes stay public (the UI prompts for the token). `Content-Type: application/json`. CORS: `Access-Control-Allow-Origin: *`, `Access-Control-Allow-Headers: Authorization`.

When WiFi credentials are not saved yet, control APIs (`/anim`, `/test/*`) return **503** `{"ok":false,"error":"wifi not configured"}`. Setup routes (`/`, `/config`, `/auth`, `/health`, `/settings`, `/setup/servo`, `/setup/led`, `/setup/audio`, `/setup/oled`) stay available on the setup AP.

If boot WiFi credentials are missing, the device opens setup AP mode (`TinyEngineer-XXXX`) and serves a five-step setup wizard at `/config` (servo calibration, OLED orientation, RGB LED, speaker test, then Wi-Fi). If saved credentials fail, it reopens setup AP mode. Hardware tests: [`docs/hardware/testing.md`](hardware/testing.md). How to wire this API into AI tools: [`integration.md`](integration.md).

Firmware answers mDNS A and AAAA (IPv6 link-local) so macOS does not wait 2–3s on a missing AAAA. If a client still pauses on the hostname, force IPv4 (`curl -4`). The IP on the OLED skips DNS entirely.

## Endpoints

### `GET /`

HTML endpoint index. Lists all routes plus supported parameters for `/anim`, `/settings`, `/test/servo`, `/setup/servo`, `/setup/led`, `/setup/audio`, and `/setup/oled`. Safe, no hardware side effects. Always public (no Bearer required).

Open in a browser:

```bash
curl http://tiny-engineer.local/
```

Returns `Content-Type: text/html; charset=utf-8`.

### `GET /auth`

Whether API auth is required. Always public. Safe, no hardware side effects. Does not reveal the token.

```bash
curl http://tiny-engineer.local/auth
```

```json
{ "ok": true, "required": false, "wifi_configured": true, "provisioning": false }
```

| Field | Meaning |
| --- | --- |
| `ok` | Always `true` on this route |
| `required` | `true` when a non-empty access token is configured |
| `wifi_configured` | `true` when WiFi credentials are saved in NVS |
| `provisioning` | `true` when the setup AP is active |

### `GET /health`

Health. Safe, no hardware side effects. Uses live `WiFi.status()`, not the boot-time flag. Requires Bearer when auth is enabled.

```bash
curl http://tiny-engineer.local/health
curl -H "Authorization: Bearer YOUR_TOKEN" http://tiny-engineer.local/health
```

```json
{
  "ok": true,
  "uptime_ms": 12345,
  "free_heap": 120000,
  "heap_size": 320000,
  "cpu_temp_c": 41.2,
  "wifi": {
    "connected": true,
    "ip": "192.168.1.10",
    "rssi": -42,
    "hostname": "tiny-engineer.local"
  },
  "wifi_configured": true,
  "provisioning": false,
  "setup_ap_ssid": "",
  "setup_ap_ip": "",
  "oled": true
}
```

| Field | Meaning |
| --- | --- |
| `ok` | Always `true` on this route |
| `uptime_ms` | `millis()` since boot |
| `free_heap` | `ESP.getFreeHeap()` — bytes available for allocation |
| `heap_size` | `ESP.getHeapSize()` — total heap bytes; usage % = `(1 - free_heap / heap_size) × 100` |
| `cpu_temp_c` | ESP32-C3 on-die temperature in °C (not ambient); `null` if the sensor is unavailable |
| `wifi.connected` | `WiFi.status() == WL_CONNECTED` |
| `wifi.ip` | STA IPv4, or `""` if down |
| `wifi.rssi` | dBm, or `0` if down |
| `wifi.hostname` | mDNS name from settings (`{hostname}.local`, default `tiny-engineer.local`) |
| `wifi_configured` | `true` when WiFi credentials are saved in NVS |
| `provisioning` | `true` when setup AP mode is active |
| `setup_ap_ssid` | Setup AP SSID when `provisioning` is true, else `""` |
| `setup_ap_ip` | Setup AP IP when `provisioning` is true (usually `192.168.4.1`), else `""` |
| `oled` | SSD1306 probed and initialized |

### `GET /settings`

Persistent settings from NVS. Safe, no hardware side effects. Developer guide for adding settings: [`settings.md`](settings.md).

```bash
curl http://tiny-engineer.local/settings
```

```json
{
  "ok": true,
  "sleep_timeout": 10,
  "hostname": "tiny-engineer",
  "volume": 70,
  "welcome": true,
  "serial_log": false,
  "continuous_timeout": 5,
  "loading": "progress",
  "eyes_style": "classic",
  "access_token_set": false,
  "wifi_configured": true,
  "wifi_ssid": "MyNetwork",
  "wifi_password_set": true,
  "servo_mins": [60, 40, 45, 35, 40],
  "servo_maxs": [130, 130, 135, 125, 130],
  "rgb_order": "GRB",
  "oled_rotate_180": false
}
```

| Field | Meaning |
| --- | --- |
| `sleep_timeout` | Minutes of continuous animation `none` before OLED blanks (default **10**). Any non-idle animation keeps the device awake and restarts the idle clock when returning to `none`. Other APIs do not affect the timer. |
| `hostname` | DHCP/mDNS label without `.local` (default **`tiny-engineer`**) |
| `volume` | Speaker gain percent for tones and WAV playback (default **70**) |
| `welcome` | Play welcome animation on boot when Wi-Fi connects (default **true**). Also enables head/neck motion during `sleep_inertia` loading |
| `serial_log` | USB serial debug logging (default **false**). When off, diagnostic `Serial` output is suppressed |
| `continuous_timeout` | Minutes a continuous animation (`typing` / `reading` / `thinking`) may run before the firmware switches to `attention` then idle (default **5**) |
| `loading` | Boot loading screen: `progress` (bar + large IP for 3 s) or `sleep_inertia` (eyes wake; no bar/IP). Default **`progress`**. Applies on **next reboot** |
| `eyes_style` | OLED eyes look: `classic` (procedural rounded eyes), `kaomoji` (animated faces), `cover` (full-half bars for an eye-hole mask), or `dots` (12×12 circles). Default **`classic`**. Applies **immediately**. Classic, cover, and dots sequences are described under [`POST /anim`](#post-anim); kaomoji face mapping is under [Kaomoji eyes](#kaomoji-eyes); cover drawing is under [Cover eyes](#cover-eyes); dots drawing is under [Dots eyes](#dots-eyes) |
| `access_token_set` | `true` when a non-empty access token is stored (secret itself is never returned) |
| `wifi_configured` | `true` when a WiFi SSID is saved |
| `wifi_ssid` | Saved network name (password is never returned) |
| `wifi_password_set` | `true` when a non-empty WiFi password is saved |
| `servo_mins` | Per-joint safe minimum degrees `[head, neck, left, right, body]` (stock defaults **60, 40, 45, 35, 40**) |
| `servo_maxs` | Per-joint safe maximum degrees (stock defaults **130, 130, 135, 125, 130**). Each max must be greater than the matching min |
| `rgb_order` | Onboard WS2812 wire-byte order (`RGB`, `RBG`, `GRB`, `GBR`, `BRG`, `BGR`). Default **`GRB`**. Survives factory reset |
| `oled_rotate_180` | OLED 180° rotation (`true` → `setRotation(2)`). Default **`false`**. Setup AP only. Survives factory reset |

### `POST /settings`

Update one or more settings. Query params. Values are written to NVS. `sleep_timeout`, `volume`, `welcome`, `serial_log`, `continuous_timeout`, `eyes_style`, and `access_token` apply immediately; a changed `hostname` or `loading` takes effect on the **next reboot**. WiFi credentials (`wifi_ssid` + `wifi_password`) are accepted **only in setup AP mode**; they are **tested before save**; on success the device connects to the home network and returns `wifi_connect_success`, `wifi_ip`, and `wifi_hostname`. `hostname` may be sent with those WiFi params (same validation as Config); it is saved before the STA connect so mDNS uses the chosen name immediately. Outside setup AP → **400** `wifi setup only in AP mode`. Servo ranges (`servo_mins` + `servo_maxs`) are also **setup AP only**; they apply immediately to motion clamps. Outside setup AP → **400** `servo setup only in AP mode`. RGB LED mapping (`rgb_order`) is **setup AP only** and applies immediately to the onboard LED. Outside setup AP → **400** `rgb setup only in AP mode`. OLED rotation (`oled_rotate_180`) is **setup AP only** and applies immediately to the display. Outside setup AP → **400** `oled setup only in AP mode`. Requires Bearer when auth is enabled.

```bash
curl -X POST "http://tiny-engineer.local/settings?sleep_timeout=2"
curl -X POST "http://tiny-engineer.local/settings?hostname=desk-bot"
curl -X POST "http://tiny-engineer.local/settings?volume=40"
curl -X POST "http://tiny-engineer.local/settings?welcome=0"
curl -X POST "http://tiny-engineer.local/settings?serial_log=1"
curl -X POST "http://tiny-engineer.local/settings?continuous_timeout=10"
curl -X POST "http://tiny-engineer.local/settings?loading=sleep_inertia"
curl -X POST "http://tiny-engineer.local/settings?eyes_style=kaomoji"
curl -X POST "http://tiny-engineer.local/settings?access_token=secret"
curl -X POST "http://tiny-engineer.local/settings?access_token="
curl -X POST "http://192.168.4.1/settings?wifi_ssid=MyNetwork&wifi_password=secret&hostname=desk-bot"
curl -X POST "http://192.168.4.1/settings?servo_mins=60,40,45,35,40&servo_maxs=130,130,135,125,130"
curl -X POST "http://192.168.4.1/settings?rgb_order=GRB"
curl -X POST "http://192.168.4.1/settings?oled_rotate_180=1"
curl -X POST "http://tiny-engineer.local/settings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"
```

```json
{
  "ok": true,
  "sleep_timeout": 1,
  "hostname": "desk-bot",
  "volume": 70,
  "welcome": true,
  "serial_log": false,
  "continuous_timeout": 5,
  "loading": "progress",
  "eyes_style": "classic",
  "access_token_set": true,
  "wifi_configured": true,
  "wifi_ssid": "MyNetwork",
  "wifi_password_set": true,
  "servo_mins": [60, 40, 45, 35, 40],
  "servo_maxs": [130, 130, 135, 125, 130],
  "rgb_order": "GRB",
  "oled_rotate_180": false,
  "wifi_connect_success": true,
  "wifi_ip": "192.168.1.10",
  "wifi_hostname": "desk-bot.local",
  "reboot_required": true
}
```

| Param | Type | Range |
| --- | --- | --- |
| `sleep_timeout` | integer | 1–1440 minutes (positive) |
| `hostname` | string | 1–31 chars, `[A-Za-z0-9-]`, not starting/ending with `-` |
| `volume` | integer | 0–100 percent |
| `welcome` | integer | `0` or `1` (boot welcome animation) |
| `serial_log` | integer | `0` or `1` (USB serial debug logging) |
| `continuous_timeout` | integer | 1–1440 minutes (positive) |
| `loading` | string | `progress` or `sleep_inertia` |
| `eyes_style` | string | `classic`, `kaomoji`, `cover`, or `dots` |
| `access_token` | string | 0–64 printable ASCII; empty string clears the token and disables auth |
| `wifi_ssid` | string | 1–32 chars; setup AP only; must be sent with `wifi_password` |
| `wifi_password` | string | 0–63 chars; setup AP only; empty allowed for open networks; tested before save |
| `servo_mins` | string | Five comma-separated integers `0`–`180` (`head,neck,left,right,body`); setup AP only; must be sent with `servo_maxs` |
| `servo_maxs` | string | Five comma-separated integers `0`–`180`; setup AP only; each value must be greater than the matching min |
| `rgb_order` | string | `RGB`, `RBG`, `GRB`, `GBR`, `BRG`, or `BGR`; setup AP only; default `GRB` |
| `oled_rotate_180` | integer | `0` or `1`; setup AP only; default `0` |

At least one param required. Invalid or missing-all → **400**. WiFi params outside setup AP → **400** `wifi setup only in AP mode`. Servo range params outside setup AP → **400** `servo setup only in AP mode`. RGB order outside setup AP → **400** `rgb setup only in AP mode`. OLED rotation outside setup AP → **400** `oled setup only in AP mode`. WiFi test failure → **400** with error such as `SSID not found`, `Auth failed`, or `Timeout`. `reboot_required` is present and `true` only when the saved hostname differs from the one used at this boot. After successful WiFi save, `wifi_connect_success`, `wifi_ip`, and `wifi_hostname` are included.

### `POST /settings/reset`

Factory reset: clears the NVS `te` namespace and restores settings to compile-time defaults, including WiFi credentials. **Servo min/max, RGB LED mapping (`rgb_order`), and OLED rotation (`oled_rotate_180`) are kept.** After reset, power-cycle (or press reset) so the device reopens setup AP mode and WiFi can be configured again; the servo, screen, and LED steps are pre-filled with the saved values and can be retuned. Until reboot, credentials are cleared in NVS but the radio may still be on the previous STA network. No query params. Requires Bearer when auth is enabled. Same JSON shape as `GET /settings`; includes `reboot_required` when the boot hostname, loading screen, or saved WiFi differed from defaults before reset.

The Config web UI clears the browser-stored Bearer token and shows a one-shot gate: power-cycle the device, then join the robot WiFi shown on the OLED and open the setup wizard. It does not poll for reconnect.

```bash
curl -X POST "http://tiny-engineer.local/settings/reset"
```

```json
{
  "ok": true,
  "sleep_timeout": 10,
  "hostname": "tiny-engineer",
  "volume": 70,
  "welcome": true,
  "serial_log": false,
  "continuous_timeout": 5,
  "loading": "progress",
  "eyes_style": "classic",
  "access_token_set": false,
  "reboot_required": true
}
```

NVS write failure → **400** `{"ok":false,"error":"factory reset failed"}`.

### `POST /test/audio`

Plays 500 / 700 / 1000 Hz on the MAX98357A (`runSoundTest()`).

```bash
curl -X POST http://tiny-engineer.local/test/audio
```

```json
{ "ok": true, "test": "audio" }
```

### `POST /test/audio/bell`

Plays `/bell.wav` from LittleFS (`playBell()`). Git source is [`assets/bell.wav`](../assets/bell.wav) (44100 Hz mono PCM); `pio run` copies it into `data/` for the filesystem image. After changing the asset, upload with `pio run -t upload` or `pio run -t uploadfs`. Do not edit `data/` by hand — the next build overwrites it.

```bash
curl -X POST http://tiny-engineer.local/test/audio/bell
```

```json
{ "ok": true, "test": "bell" }
```

If the WAV is missing or unreadable, returns **500** with `{"ok":false,"error":"bell playback failed"}`.

### `POST /test/screen`

OLED demo: title, `HELLO`, X in a box (`runOledTest()`). No-op if the panel is missing.

```bash
curl -X POST http://tiny-engineer.local/test/screen
```

```json
{ "ok": true, "test": "screen" }
```

### `POST /test/movement`

All five servos: per-joint mid → +0.5 → −0.5 → mid of the saved min/max (`runServoTest()`). Needs a strong 5 V supply — see [power.md](hardware/power.md).

```bash
curl -X POST http://tiny-engineer.local/test/movement
```

```json
{ "ok": true, "test": "movement" }
```

### `POST /test/led`

Onboard WS2812 on GPIO10: R → G → B → white → off (`runRgbTest()`), then fades back to the current animation color (see [RGB LED](#rgb-led)).

```bash
curl -X POST http://tiny-engineer.local/test/led
```

```json
{ "ok": true, "test": "led" }
```

### `POST /setup/servo`

Setup AP only. Slowly move one servo, or all five to 90°, using the full **0–180°** electrical range (no saved safe-range clamp). ~25°/s (`SERVO_CALIB_SPEED_DEG_S`). Used by the setup wizard for seating printed parts at 90° and for range finding. Handler blocks until the move finishes. Does **not** require Wi-Fi credentials. Outside provisioning → **400** `setup servo only in AP mode`.

Either `all=90`, or `index` + `angle`.

| Param | Type | Range |
| --- | --- | --- |
| `all` | integer | `90` (every joint to 90°) |
| `index` | integer | `0`–`4` (required with `angle` when `all` is omitted) |
| `angle` | number | `0`–`180` |

```bash
curl -X POST "http://192.168.4.1/setup/servo?all=90"
curl -X POST "http://192.168.4.1/setup/servo?index=0&angle=90"
```

```json
{ "ok": true, "setup": "servo", "index": 0, "angle": 90 }
```

Wrong params return **400** and do not move any servo:

| `error` | When |
| --- | --- |
| `setup servo only in AP mode` | Not in setup AP |
| `invalid all` | `all` present but not `90` |
| `missing index or angle` | Neither `all=90` nor both `index` and `angle` |
| `invalid index` | Non-integer `index` |
| `index out of range` | `index` outside `0`–`4` |
| `invalid angle` | Non-numeric `angle` |
| `angle out of range` | `angle` outside `0`–`180` |

After STA is up, use `POST /test/servo` (clamped to saved min/max).
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

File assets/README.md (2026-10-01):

# Assets

Source files for Tiny Engineer branding and speaker clips. Firmware does not read this folder at runtime.

## Audio

WAV clips played by animations and the setup wizard. Format: **44100 Hz, mono, 16-bit PCM**.

`pio run` copies these files into `data/` via [`scripts/copy_assets.py`](../scripts/copy_assets.py). The next filesystem image overwrites `data/`, so edit the files here. Flash them with `pio run -t upload` or `pio run -t uploadfs`.

`custom_audio_mod` in [`platformio.ini`](../platformio.ini) is empty by default, so this folder is the whole image. Set it to a mod name to overlay `mods/<name>/assets/*.wav` on top of these files. Clips the mod omits stay the files below. See [docs/flash.md](../docs/flash.md).

| File | Duration | Transcript |
| --- | --- | --- |
| [`abort.wav`](abort.wav) | 2.5 s | Fine! I didn't want to finish that anyway! |
| [`attention.wav`](attention.wav) | 3.0 s | Psst, Human! I might want to take a look. |
| [`bell.wav`](bell.wav) | 2.0 s | Bell sound, no voiceover. |
| [`dead.wav`](dead.wav) | 3.4 s | Insufficient resources, shutting dooooowwwwwnnnn.... |
| [`error.wav`](error.wav) | 2.2 s | O-oh, human! We have a problem! |
| [`welcome.wav`](welcome.wav) | 2.7 s | Hello human! What are we building today? |

Animation timing is synced to these clips. After replacing a file, check the matching pose in `src/animation/`. Playback details: [docs/api.md](../docs/api.md).
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

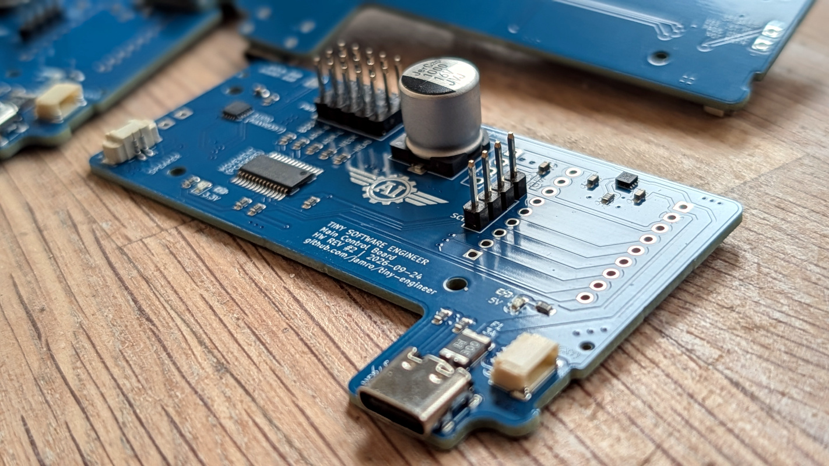
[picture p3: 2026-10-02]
hardware/boards/main-control-board/main-control-board-rev-2-preview.jpg

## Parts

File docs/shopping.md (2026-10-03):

# Shopping list

Buy this before you print or connect. Electrical spec (voltages, limits, pin notes): [hardware/components.md](hardware/components.md). Screw lengths in assembly steps: [3d_models/README.md → Screws](../3d_models/README.md#screws). Build order: [getting-started.md](getting-started.md).

## Servo size (pick first)

> **First build:** buy **five Tower Pro SG90** (or equivalent 9 g analog micros). Print [`3d_models/parts/sg90/`](../3d_models/parts/sg90/3mf/). Do **not** open Fusion.

Servo size sets the size of the **whole robot**. Buy five of **one** model, then print (or order) the matching `parts/{servo_id}/` folder.

| Choice | When | Print folder |
| --- | --- | --- |
| **Tower Pro SG90** (recommended) | Default. Bigger desk — electronics are easier to fit | [`parts/sg90/`](../3d_models/parts/sg90/3mf/) |
| **Feetech FS0307** | Compact robot | [`parts/fs0307/`](../3d_models/parts/fs0307/3mf/) |
| **PowerHD HD-1370A** | Backward compatibility only — skip for a new build | [`parts/hd1370a/`](../3d_models/parts/hd1370a/3mf/) |

Non-preset servo: measure it, add a preset, export parts — [parametric design](3d/parametric-design.md).

## Electronics

The default build uses the **main control board**. PCA9685, the audio amp, and USB-C are on that PCB. You plug in the ESP32, OLED, five servos, and the speaker.

Order the open-source board from any fab: [hardware/order-main-control-board.md](hardware/order-main-control-board.md). Connect it: [hardware/main-control-board.md](hardware/main-control-board.md). A cheaper assembled batch may show up later: [discussion #50](https://github.com/jamro/tiny-engineer/discussions/50). Fab lead time is part of ordering the board.

### Default cart

| Part | Qty | Link / notes |
| --- | --- | --- |
| Tiny Engineer main control board | 1 | KiCad in [`hardware/boards/main-control-board/`](../hardware/boards/main-control-board/) ([CERN-OHL-S](../3d_models/LICENSE)). Order: [hardware/order-main-control-board.md](hardware/order-main-control-board.md). |
| Waveshare ESP32-C3-Zero | 1 | https://docs.waveshare.com/ESP32-C3-Zero |
| Tower Pro SG90 (or equivalent 9 g analog micro) | 5 | Widely available hobby servo — no single canonical SKU |
| [Adafruit Mini Oval Speaker - 8 Ohm 1 Watt](https://www.adafruit.com/product/3923) | 1 | https://www.adafruit.com/product/3923 |
| [Waveshare 0.91inch OLED Module](https://www.waveshare.com/0.91inch-oled-module.htm) (SSD1306, 128×32, I2C) | 1 | https://www.waveshare.com/0.91inch-oled-module.htm |

Compact build: swap the five SG90 for **Feetech FS0307** (same qty). Do not mix models.

The board already includes the PCA9685, the MAX98357A, and USB-C.

### Advanced: extra modules

Use separate breakouts when you want modules the main control board does not support. Same firmware and printed Desk. More soldering and more boards in the cavity. Wiring: [hardware/wiring.md](hardware/wiring.md). Desk mounting: [3d/assembly-modular.md](3d/assembly-modular.md).

| Part | Qty | Link |
| --- | --- | --- |
| Adafruit PCA9685 16-channel PWM servo driver | 1 | https://www.adafruit.com/product/815 |
| MAX98357A I2S class-D mono amplifier | 1 | https://www.aliexpress.us/item/3256805196806369.html |
| Adafruit 5993 USB-C breakout | 1 | https://www.adafruit.com/product/5993 |

These three replace the main control board. You still buy the ESP32, servos, speaker, and OLED from the default cart.

### Fasteners

M2 thread-forming (self-tapping) screws for plastic, **pan-head or button-head**. Qty below is the shopping list; per-step placement stays in [3d_models/README.md → Screws](../3d_models/README.md#screws).

| Item | Qty |
| --- | --- |
| M2×4 mm | 8 |
| M2×8 mm | 27 |
| M2×16 mm | 15 |
| M2 nuts | 6 |
| Servo bag screws | 5 (come with the servos) |

The six `BottomCover` screws are included in the M2×8 total. Their heads must be at most **4.0 mm diameter × 2.0 mm high** to fit the recessed pockets.

An M2 assortment covering **M2×4–M2×16** is the easy path. Nearby lengths often work; test-fit if you substitute.

### Power and cables

| Item | Qty | Notes |
| --- | --- | --- |
| **5 V / ≥2 A** USB supply (or a host that can actually deliver that) | 1 | Five stalled servos plus Wi-Fi and audio need headroom. A 1 A phone charger will brown out. |
| USB-C **data** cable | 1 | Charge-only cables fail flash and serial. |

### Printed parts

Home printer: **PLA** or **PETG**, testers first — [3d_models/README.md](../3d_models/README.md). No printer: [order printed parts](3d/order-parts.md).

## Next

Return to the [getting-started](getting-started.md) checklist ([§1 Shop](getting-started.md#1-shop) done). Then print or order.

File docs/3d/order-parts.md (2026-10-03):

# Order printed parts (no 3D printer)

No printer at home? You can still get the printed set from a third-party 3D-printing service, then return to the [getting-started](../getting-started.md) checklist. Mechanical joins: [assembly.md](assembly.md).

Orders are at your own risk. Fit and finish can vary by provider and by design revision — especially on development builds there may be bugs — and we cannot guarantee every part will match every time.

## Provider

Any FDM bureau that accepts STL or STEP can work. **[PCBWay 3D printing](https://www.pcbway.com/rapid-prototyping/3d-printing/)** is one example that was [partially tested](https://github.com/jamro/tiny-engineer/issues/9).

## Which files to upload

1. Pick the servo folder that matches the servos you bought: `3d_models/parts/<servo_id>/` ([which servo](../shopping.md)).
2. Prefer files under **`stl/`** (widely accepted). Use **`step/`** if the provider prefers CAD. **`3mf/`** is mainly for home slicers.
3. Upload these **three** aggregates only — not the full individual-part inventory. They group pieces meant for the same material / color:

| File | Role |
| --- | --- |
| `PartsSetA.stl` (or `.step`) | Originally silk copper; customize the color if you like |
| `PartsSetB.stl` (or `.step`) | Originally black, including `BottomCover` and the updated `Chair`; customize the color if you like |
| `LampDiffuser.stl` (or `.step`) | White or translucent. Intentionally thin so light passes through; may fail the provider’s minimum wall-thickness check — expect to accept a wall-thickness / damage-risk disclaimer if asked |

The largest black aggregate (SG90) is approximately **235 × 332 mm**. Services can arrange the parts for their machines; on a smaller home print bed, use the individual files instead.

## Settings used in the PCBWay test

Starting point (adjust if your provider’s options differ):

| Setting | Value |
| --- | --- |
| Process | 3D printing / **PLA** (PETG should work; other materials not tested here) |
| Colors | Black / Silk Copper / White |
| Infill | **20%** |
| Threads and tapped holes | **No** |
| Inserts | **No** |

## How to place the order

UI labels change; follow the outcomes, not exact button names. The flow below matches a typical PCBWay-style quote.

1. Create or sign in to an account on the provider’s **3D printing** quote page (not PCB or CNC).
2. Start a new **3D printing / FDM** quote.
3. Upload the three files from the matching `stl/` (or `step/`) folder: `PartsSetA`, `PartsSetB`, `LampDiffuser`. Confirm units are **mm** if asked.
4. For each file, set material (PLA or PETG), color (copper-ish / black / white-or-translucent), **20%** infill, no threads, no inserts.
5. For `LampDiffuser`, if the provider flags thin walls, accept the wall-thickness risk option (wording varies) so the quote can proceed.
6. Review the quote. Printing cost and shipping are separate — shipping can dominate for a single set.
7. Submit the request, wait for technical review / approval, pay, then track shipment.
8. When the parts arrive, dry-fit the servos and M2 screws before full assembly. If you notice that the holes for the screws are too loose, you can gently wrap a small piece of tape (for example, masking tape or electrical tape) around the screw, or place a tiny piece of paper inside the hole before inserting the screw. This will help the screw grip better. Make sure everything fits as expected before final assembly.

## Next steps

Return to the [getting-started](../getting-started.md) checklist ([§2 Print or order](../getting-started.md#2-print-or-order) done). Next on that list is **connect**, then flash, then one assembly run. Part inventory and home-print notes: [3d_models/README.md](../../3d_models/README.md).

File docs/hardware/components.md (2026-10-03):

# Hardware inventory

Buyers: start at [shopping.md](../shopping.md). The default build has the PCA9685, the MAX98357A, and USB-C on the [main control board](main-control-board.md). This page is the electrical spec for those chips and the plug-in modules (ESP32, servos, OLED, speaker). Breakout SKUs are the advanced path — [wiring.md](wiring.md).

Selected hardware only. Substituting a part means updating this file, [pinout.md](pinout.md), and either the board design or [wiring.md](wiring.md). Servo *model* may be any preset in [`servos.json`](../../3d_models/fusion/TinyEngineerTools/servos.json) if the printed parts match — [parametric design](../3d/parametric-design.md).

Constants cited below match [`include/pins.h`](../../include/pins.h).

## Product links

| Part | Link |
| --- | --- |
| Waveshare ESP32-C3-Zero | https://docs.waveshare.com/ESP32-C3-Zero |
| Adafruit PCA9685 breakout (advanced path) | https://www.adafruit.com/product/815 |
| Tower Pro SG90 (or equivalent) | Widely available hobby servo — no single canonical SKU |
| Feetech FS0307 | See vendor listing for FS0307 analog micro |
| PowerHD HD-1370A (backward compatibility) | https://www.chd.hk/Product_Detail.aspx?id=30 |
| MAX98357A breakout (advanced path) | https://www.aliexpress.us/item/3256805196806369.html |
| [Adafruit Mini Oval Speaker - 8 Ohm 1 Watt](https://www.adafruit.com/product/3923) | https://www.adafruit.com/product/3923 |
| Waveshare 0.91inch OLED Module | https://www.waveshare.com/0.91inch-oled-module.htm |
| Adafruit 5993 USB-C breakout (advanced path) | https://www.adafruit.com/product/5993 |

## Waveshare ESP32-C3-Zero

| Field | Value |
| --- | --- |
| Exact model | Waveshare ESP32-C3-Zero (ESP32-C3FH4) |
| Quantity | 1 |
| Purpose | Main controller: I2C, I2S, USB CDC, Wi-Fi, onboard RGB |
| Operating voltage | GPIO **3.3 V**. External power on the **5V** pad: 3.7–6 V (robot uses the +5V rail) |
| Logic | **3.3 V only** — do not drive 5 V into GPIO |
| Radio | Wi-Fi 2.4 GHz (product use). BLE present on silicon but **out of scope** |
| USB | Native USB on GPIO18/19 — reached via the main control board USB-C (onboard USB-C unused when assembled). Advanced path: Adafruit 5993 — [wiring.md](wiring.md#usb-connector-5993) |
| Flash | 4 MB stacked flash on GPIO12–GPIO17 (those GPIOs are **not exposed**) |
| Onboard RGB | WS2812 on **GPIO10** |
| Firmware notes | Boot: dim green status. Animations: white (typing/reading/thinking/welcome/ring/wakeup), pulsing red (attention/error/dead), solid red (abort), off (idle/sleep). 1 s fade between non-pulse states. Fatal init errors: hang and blink red (1 = PCA9685, 2 = I2S). See [blink codes](testing.md#boot-failure-blink-codes) and [`docs/api.md`](../api.md#rgb-led) |
| BOOT | Button / strapping on **GPIO9** |
| RESET | Separate RESET button (CHIP_EN), not a GPIO |
| UART0 silkscreen | TX = GPIO21, RX = GPIO20 |
| USB D− / D+ | GPIO18 / GPIO19 (native USB) |
| 3V3 regulator | Onboard LDO (Waveshare: ME6217C33M5G). For **logic loads only** |
| Important pins | See [pinout.md](pinout.md) |
| Limits | Do not power servos from **3V3**. Do not cover the ceramic antenna with metal, PCB, or plastic. |
| Firmware note | PlatformIO `board = esp32-c3-devkitm-1` is a **build target**, not the physical module. Physical board is C3-Zero. |

## Adafruit PCA9685 16-channel PWM servo driver

| Field | Value |
| --- | --- |
| Exact model | PCA9685 on the main control board. Advanced path: Adafruit 16-Channel 12-bit PWM/Servo Driver breakout |
| Quantity | 1 |
| Purpose | Independent 50 Hz servo PWM so ESP32 timing is not the PWM source |
| Operating voltage | **VCC** (logic): 3.3 V from ESP32 **3V3**. **V+** (servos): +5V rail |
| Interface | I2C |
| Address | `0x40` (`PCA9685_ADDRESS` in firmware). A0–A5 pads can change this |
| PWM | 12-bit, firmware `setPWMFreq(50)` |
| Important pins | As drawn: **5V** (servo-rail in), **V+** (to servo 5V), **VCC** (3V3 logic), **GND**, **SDA**, **SCL**, **PWM**, **OE** (GP5, active LOW) |
| Channels used | 0–4 (five servos). 5–15 unused |
| Limits | **V+** and **VCC** must stay separate. Do not jumper servo power onto logic VCC on this robot |
| Firmware note | Detection at `0x40` is a **hard fail** in the bring-up test |

## Analog micro servos (qty 5)

Five analog micro servos drive the joints (Head / Neck / L hand / R hand / Body — [robot-movement.md](../robot-movement.md)). Buy **five of one model**. Print the matching `parts/{servo_id}/3mf/` folder. Which size to pick: [parametric design](../3d/parametric-design.md).

Shared for every preset:

| Field | Value |
| --- | --- |
| Quantity | 5 (one model) |
| Operating voltage | Robot: **+5V** via PCA9685 **V+** |
| Interface | Analog PWM, ~50 Hz. Signal is 3.3 V from PCA9685 — acceptable for this servo class |
| Pulse | Neutral ~1500 µs. Firmware window **800–2200 µs** (`SERVO_MIN_US` / `SERVO_MAX_US`) |
| Important pins | SIG, +5V, GND (JR-style 3-wire) |

> [!WARNING]
> Never power the servos from the ESP32 3.3 V regulator.

Firmware uses **per-servo safe ranges** in [`include/servos.h`](../../include/servos.h) (`SERVO_SPECS`). Tune after assembly if needed. Do not command full 0–180° / 800–2200 µs on the assembled robot. See [servos.md](servos.md).

### Tower Pro SG90 (recommended)

Easiest to buy. Larger body → larger printed robot; electronics are easier to fit in the desk.

| Field | Value |
| --- | --- |
| Exact model | Tower Pro SG90 analog micro (or equivalent 9 g class) |
| `servo_id` | `sg90` |
| Size | Larger than FS0307 / HD-1370A — see [`servos.json`](../../3d_models/fusion/TinyEngineerTools/servos.json) |

Print [`3d_models/parts/sg90/3mf/`](../../3d_models/parts/sg90/3mf/).

### Feetech FS0307

More compact. Use this if you want a smaller robot that looks tighter on the desk.

| Field | Value |
| --- | --- |
| Exact model | Feetech FS0307 analog micro servo |
| `servo_id` | `fs0307` |

Print [`3d_models/parts/fs0307/3mf/`](../../3d_models/parts/fs0307/3mf/).

### PowerHD HD-1370A (backward compatibility)

Still supported. Not the pick for a new build.

Print [`3d_models/parts/hd1370a/3mf/`](../../3d_models/parts/hd1370a/3mf/).

| Field | Value |
| --- | --- |
| Exact model | PowerHD HD-1370A analog micro servo |
| `servo_id` | `hd1370a` |
| Current (datasheet stall) | ~260 mA @ 4.8 V, ~320 mA @ 6.0 V |
| No-load current | ~110 mA @ 4.8 V, ~120 mA @ 6.0 V |
| Idle current | ~4 mA @ 4.8 V, ~5 mA @ 6.0 V |
| Torque / speed | 0.4 kg·cm / 0.12 s/60° @ 4.8 V; 0.6 kg·cm / 0.10 s/60° @ 6.0 V |
| Size / mass | ~20.2 × 8.5 × 17.6 mm, ~3.7 g |
| Limits | Manufacturer sheet also lists **~130°** travel over 800–2200 µs, while many retailers say 0–180°. Treat 0–180° as **nominal**, not a mechanical guarantee. |

## MAX98357A I2S class-D mono amplifier

| Field | Value |
| --- | --- |
| Exact model | MAX98357A on the main control board (I2S in, speaker out). Advanced path: breakout module |
| Quantity | 1 |
| Purpose | Digital audio → mono speaker. ESP32 never drives the speaker as GPIO PWM |
| Operating voltage | **Vin** 2.5–5.5 V. Drawing: USB **5V** → **Vin** |
| I2S logic | 3.3 V from ESP32 (compatible) |
| Interface | I2S: **BCLK**, **WS/LRC**, **DIN**. No MCLK |
| Sample rates | Chip: 8–96 kHz. Firmware: **44100 Hz**, 16-bit, stereo slot mode |
| Output power (typical) | ~1.8 W into 8 Ω @ 5 V / 10% THD (datasheet-class figure) |
| Important pins | **Vin**, **GND**, **BCLK**, **LRC**, **DIN**, **SPK+**, **SPK-**. Board gain: solder jumper ([board README](../../hardware/boards/main-control-board/README.md)). Breakout **GAIN** / **SD** left unwired (GAIN floating ≈ 9 dB, SD pulled up ≈ left channel) — [wiring.md](wiring.md) |
| Limits | Output is **BTL**. Do not connect SPK- to GND. Do not feed SPK+/SPK- into another amplifier. Do not drive the speaker from ESP32 GPIO |

> [!WARNING]
> MAX98357A SPK- is not ground.

## Speaker

| Field | Value |
| --- | --- |
| Exact model | [Adafruit Mini Oval Speaker - 8 Ohm 1 Watt](https://www.adafruit.com/product/3923) (8 Ω, 1 W mono) |
| Quantity | 1 |
| Purpose | Acoustic output |
| Operating voltage | Not a voltage-rail device — driven by MAX98357A BTL |
| Interface | Two terminals → **SPK+** and **SPK-** |
| Limits | 1 W rated. Amp can theoretically exceed 1 W into 8 Ω at 5 V; keep firmware volume moderate. Never connect either terminal to **GND** |

Speaker wiring is **not** drawn on `docs/wiring/Tiny Engineer.drawio`. Electrical rule is still: speaker ↔ SPK+/SPK- only.

## Waveshare 0.91inch OLED Module (SSD1306, I2C)

| Field | Value |
| --- | --- |
| Exact model | [Waveshare 0.91inch OLED Module](https://www.waveshare.com/0.91inch-oled-module.htm) (SKU 14657). Driver SSD1306, 128×32, I2C |
| Quantity | 1 |
| Purpose | Status / test UI |
| Operating voltage | Module accepts **3.3 V / 5 V**. Robot **VCC** from ESP32 **3V3** (confirmed in [`docs/wiring`](../wiring/Tiny%20Engineer.drawio.png)) |
| Interface | I2C on the shared bus. Pads **VCC**, **GND**, **SDA**, **SCL** |
| Address | **`0x3C`** (`OLED_ADDRESS` in firmware). Alternate 0x3D exists on some modules if the ADDR jumper is changed — not used here |
| Resolution | 128×32 (`OLED_WIDTH` / `OLED_HEIGHT`) |
| Important pins | **VCC**, **GND**, **SDA**, **SCL**. Clock pad on this board is **SCL**. The wiring PNG may still label that net **SCK** (generic clone silkscreen) — same I2C clock, ESP32 **GP1** |
| Firmware notes | `SSD1306_SWITCHCAPVCC`; rotation from `oled_rotate_180` (`setRotation(0)` or `2`). Missing OLED is **non-fatal** in the bring-up test |
| Limits | Robot wiring is **3V3**. Do not hang this module on the servo +5V rail |

## USB-C

Default connector is on the main control board — [power.md](power.md), [main-control-board.md](main-control-board.md). Advanced path: Adafruit 5993 — [wiring.md](wiring.md#usb-connector-5993).

## Mechanical / RF notes for firmware and CAD

- Keep metal and dense plastic **off** the ESP32 ceramic antenna area.
- Servo horns and end stops: start from `SERVO_SPECS` in [`include/servos.h`](../../include/servos.h); tune after installation if needed. Assembled motion stays inside the saved min/max.
- GPIO18/19 are native USB via the main control board USB-C (or the 5993 on the advanced path). Leave them assigned while using USB CDC for flash/serial.

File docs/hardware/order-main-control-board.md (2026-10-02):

# Order the main control board

Build the integrated PCB yourself from the open-source KiCad design, then return to the [getting-started](../getting-started.md) checklist. After the boards arrive, connect modules with [main-control-board.md](main-control-board.md).

**Any PCB manufacturer can fabricate this board.** Upload formats, BOM / pick-and-place conventions, assembly options, and part stock differ by fab. If you use someone other than the provider below, adapt the steps to their process and always re-check the bill of materials and part availability before you pay for assembly.

This walkthrough uses **[JLCPCB](https://jlcpcb.com/)** as one common place to order PCB + assembly (PCBA) with LCSC parts. Tiny Engineer has **no partnership** with JLCPCB — the project documents one provider the author chose; you are free to use another.

Orders are at your own risk. Fabrication and assembly can go wrong (missing parts, wrong orientation, stock substitutions). Design revisions — especially early boards — can have bugs. The project cannot guarantee every order yields a working board.

## What you still buy separately

The fab builds the PCB and (if you choose PCBA) the parts soldered onto it. You still need the plug-in modules and the rest of the robot cart: [shopping.md](../shopping.md).

## Prerequisites

- **KiCad 10** (project major — see [pcb.md](../pcb.md))
- KiCad **Fabrication Toolkit** plugin (Plugin and Content Manager → search for Fabrication Toolkit). It exports Gerbers plus JLCPCB-oriented BOM and position files.
- An account at your chosen fab (here: JLCPCB)

## 1. Export manufacturing files from KiCad

1. Open [`hardware/boards/main-control-board/main-control-board.kicad_pro`](../../hardware/boards/main-control-board/main-control-board.kicad_pro).
2. Run **Fabrication Toolkit** so it writes manufacturing outputs under the board folder (typically a `production/` directory).
3. Confirm you have at least:
   - a Gerber **ZIP** (board layers + drills)
   - **`bom.csv`** (bill of materials)
   - **`positions.csv`** (component placement / CPL / pick-and-place)
4. Keep `production/` local — it is gitignored and should not be committed.

UI names for the plugin and export dialog change over time; what matters is those three artifacts.

## 2. Choose how much assembly you want

| Option | Cost / effort | This guide |
| --- | --- | --- |
| **PCB only** | Cheapest. You solder every SMD part yourself. | **Not recommended** for a first order — small SMD work is hard. **Skipped** below. |
| **PCBA, one side (top)** | Good cost compromise. Most electronics are on the front; you solder the ESP32 sockets yourself. | Covered |
| **PCBA, both sides** | Most expensive, most convenient — no soldering needed for the board parts. | Covered |

On **one-side** PCBA, the remaining hand work is soldering **2.54 mm female header** sockets for the Waveshare ESP32-C3-Zero (two 1×9 rows on this design). On **both-sides** PCBA, those headers are assembled for you.

## 3. Place the order (JLCPCB example)

Site menus and labels change. Follow the **outcomes**, not exact button names.

1. Create or sign in to a JLCPCB account and start a new **PCB** order.
2. Upload the Gerber **ZIP** from Fabrication Toolkit.
3. Keep most board options at sensible defaults. As of writing, a typical match for this board is:

   | Setting | Typical choice |
   | --- | --- |
   | Base material | FR-4 |
   | Layers | 2 |
   | Thickness | 1.6 mm |
   | Quantity | Fab minimum if you only need one board (often **5** today) |
   | PCB color | Your choice — colors other than green can cost more |
   | Surface finish | LeadFree HASL (author preference; other finishes are fine if the fab offers them) |

4. **Turn on PCB Assembly.** Leave stencil **off** for this PCBA flow — you do not need a separate stencil when the fab assembles the board.
5. Set assembly options for your path:

   **One side (you solder ESP32 headers later)**

   - PCBA type: **Economic**
   - Assembly side: **Top**
   - Assembly quantity: the fab may let you assemble **fewer** boards than the PCB quantity (for example, assemble 2 of 5). Bare leftovers arrive without parts. Assembling every board costs more but gives working spares; fewer assemblies is a valid way to cut cost.

   **Both sides (fully assembled)**

   - PCBA type: **Standard**
   - Assembly side: **Both sides**
   - For this process the fab may add **edge rails**. Enabling a **depaneling** service is often worth it so you get usable boards without cutting rails yourself.
   - Same note on assembly quantity vs PCB quantity as above.

6. Continue and **review the board layout** in the fab’s viewer. Confirm outline, holes, and copper look right, then proceed.
7. Upload **`bom.csv`** and **`positions.csv`** (the CPL / pick-and-place file), then continue.
8. **Review the bill of materials.** Stock and catalog entries change. Check every line. ESP32 header parts may warn that **multiple catalog items match** — pick the correct one manually. Resolve out-of-stock or wrong parts here (or update the schematic LCSC fields, re-export, and upload again) before you pay.
9. **Review component placement and orientation**, then continue.
10. **Review the cost quote**, complete checkout, and track the shipment.

## 4. When the boards arrive

1. Inspect for missing parts, tombstoned components, or obvious orientation mistakes.
2. **One-side PCBA:** solder the 2.54 mm female headers for the ESP32, then follow [main-control-board.md](main-control-board.md).
3. **Both-sides PCBA:** plug in the ESP32, OLED, servos, and speaker per [main-control-board.md](main-control-board.md) — no board soldering required for those sockets.
4. Return to [getting-started](../getting-started.md) for flash and mechanical assembly.

KiCad sources and electrical notes for contributors: [`hardware/boards/main-control-board/`](../../hardware/boards/main-control-board/). Contribution rules: [pcb.md](../pcb.md). Optional cheaper community batch: [discussion #50](https://github.com/jamro/tiny-engineer/discussions/50).

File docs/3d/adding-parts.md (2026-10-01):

# Adding parts to the CAD

Contributor workflow for new printable geometry in [`3d_models/cad/TinyEngineer.f3d`](../../3d_models/cad/TinyEngineer.f3d). For servo presets and add-in install, see [parametric design](parametric-design.md). For builders printing existing parts, see [`3d_models/README.md`](../../3d_models/README.md).

```mermaid
flowchart TD
  design["Design parametric part"]
  test["Servo Configurator: all presets"]
  layout["Copy into PRINT_LAYOUT"]
  set["Add to PartsSet"]
  export["Parts Exporter: all servos"]
  design --> test --> layout --> set --> export
```

## Design rules

### Source of truth

Edit [`cad/TinyEngineer.f3d`](../../3d_models/cad/TinyEngineer.f3d) only. Never hand-edit `.3mf`, `.stl`, or `.step` exports — those are the release binaries. Change the Fusion source, then re-export.

### Parametric, multi-servo

Drive dimensions from Fusion **user parameters** (servo presets in [`servos.json`](../../3d_models/fusion/TinyEngineerTools/servos.json), or other shared params). Prefer referencing existing geometry (edges, faces, projected sketches) over hard-coded lengths that only fit one servo.

The design must rebuild cleanly for **every** predefined servo. Do not ship a part that only works for SG90.

Do not invent new keys in `servos.json`. Parameter names must already exist as Fusion user parameters in the `.f3d`. Details: [Add a new servo](parametric-design.md#add-a-new-servo).

### Naming

Keep one name end to end:

- Fusion component name
- Direct child under `PRINT_LAYOUT` (what the exporter lists)
- Export basename (`Head.3mf`, …)
- Row in the [`3d_models/README.md`](../../3d_models/README.md) parts table

### Print without supports

Orient and feature the part so FDM can print it **without supports** (no large overhangs past what your bridging/chamfers already handle). The print-ready copy under `PRINT_LAYOUT` must sit on a flat face on the horizontal origin.

### `min_wall_thickness`

Use the Fusion user parameter **`min_wall_thickness`** as the floor for:

- Walls
- Thin horizontal layers / floors

That keeps parts printable at third-party services and on typical 0.4 mm-nozzle FDM setups. Do not go thinner than this parameter.

### M2 / fasteners

Assembly uses **M2** screws that thread directly into printed PLA/PETG. New screw pilots use `screw_thread_diameter` (related: `screw_head_diameter`, `screw_head_height`). Details: [M2 screw holes](parametric-design.md#m2-screw-holes).

- No heat-set inserts unless an intentional, documented exception.
- Prefer existing lengths **M2×4 / M2×8 / M2×16**.
- If a new length is required, update the screw BOM in [`3d_models/README.md`](../../3d_models/README.md) and the cart in [`docs/shopping.md`](../shopping.md).

### Clearance / fit

Design so parts and hardware fit **without sanding** as the happy path. Leave real clearance for servo bodies, horns, and moving links so joints do not bind.

## Timeline discipline

Keep the Fusion timeline readable for other contributors.

1. **One component, one block** — Create the part as a **separate component**. Keep all features that belong to that component (sketches, extrudes, fillets, holes, …) **next to** its creation on the timeline. Do not scatter edits to the same component across distant timeline positions.
2. **Components first, joints later** — Create (or finish) components first. Add joints that lock assembly positions in a **later** timeline section, after component creation.
3. **Same rule under `PRINT_LAYOUT`** — Inside `PRINT_LAYOUT`, define/copy components first; add assembly joints afterward.

## Assembly vs print layout

### Functional assembly

Joint the new component into the main robot assembly so it sits correctly relative to neighbors for all servo presets.

### Print-ready copy (`PRINT_LAYOUT`)

1. **Copy & paste** (not **Paste New**) a ready-to-print instance under the **`PRINT_LAYOUT`** component. Paste keeps the link to the source component so parametric updates stay in sync.
2. Orient it so it lies on the **horizontal origin**, print face down, **no supports**.
3. Lock it to the origin with a **joint** so the export pose stays fixed.
4. Add it to the correct **`PRINT_LAYOUT` / `PartsSet*`** aggregate for its **intended print color** only — do not mix colors in one set. Nest/place it to keep the print bed footprint realistically compact. Lock that placement with a **joint** as well.

`PartsSetA` / `PartsSetB` (and similar) are aggregates of same-color parts for [service orders](order-parts.md). Home printers usually print individual `.3mf` files instead — see [`3d_models/README.md`](../../3d_models/README.md).

## Validate every servo preset

Before you call the part done:

1. Open **Utilities → Add-Ins → TinyEngineer Servo Configurator**.
2. Switch through **all** predefined servos.
3. Confirm the **new part** and the **whole design** update without compute **errors** or **warnings** for any preset.

Fix failures for every preset, not only the one you design against.

## Export

Use **Utilities → Add-Ins → Tiny Engineer Parts Exporter** to export the new part(s) from `PRINT_LAYOUT` into the supported formats for **all** supported servos. Output lands under `3d_models/parts/{servo_id}/` (`3mf/`, `stl/`, `step/`). Details: [parametric design — Parts Exporter](parametric-design.md#tiny-engineer-parts-exporter).

Commit both the updated `.f3d` and the exported meshes/STEP for the affected servos.

## Docs, trademark, and license

After the CAD and exports land:

- **Docs sync** — new stock part → parts table in [`3d_models/README.md`](../../3d_models/README.md); color-group / aggregate change → [order-parts.md](order-parts.md); join-order change → [assembly.md](assembly.md).
- **Trademark** — do not replace or repurpose `AiEmblem` as branding. See [TRADEMARK.md](../../TRADEMARK.md).
- **License** — stock `cad/` and `parts/`, and mod geometry under `mods/<mod_name>/3d_models/{cad,parts}/`, are [CERN-OHL-S-2.0](../../3d_models/LICENSE). When distributing Products based on these designs, keep Source Location accurate per [`3d_models/NOTICE`](../../3d_models/NOTICE). For a mod, the Source Location is that mod’s `3d_models` tree.

## Optional mods

Optional elements and community mods live under [`mods/`](../../mods/README.md). Promote one into stock `cad/` and `parts/` only when it becomes core.

Place them under:

```text
mods/<mod_name>/
  README.md     # optional: what it is, non-model notes
  3d_models/
    cad/        # Fusion source for the mod
    parts/      # Exported meshes, same layout idea as 3d_models/parts/
  ...           # anything that is not a model
```

Mirror stock `3d_models` inside the mod (`cad` + `parts`). Keep CERN-OHL-S licensing consistent with [`3d_models/LICENSE`](../../3d_models/LICENSE) when you distribute Products based on these designs. Each mod may include a short `README.md` describing what it fits and which `parts/{servo_id}/` folders were exported.

Commit and PR title: `type(mods): summary` — name the mod in the summary. `feat(mods)` / `fix(mods)` do not version the stock CAD revision. Promoting a mod into stock `cad/` and `parts/` is `feat(cad)`. See [CONTRIBUTING.md](../../CONTRIBUTING.md).

## Checklist

- [ ] Source of truth: `.f3d` edited; exports re-generated (no hand-edited meshes)
- [ ] Naming: component = `PRINT_LAYOUT` child = export basename = README parts table
- [ ] Parametric (user params / referenced geometry); works for all presets
- [ ] No invented `servos.json` keys (Fusion user params first)
- [ ] Printable without supports; walls/floors ≥ `min_wall_thickness`
- [ ] M2 pilots use `screw_thread_diameter`; BOM/shopping updated if a new length is needed
- [ ] Clearance for servos, horns, and moving links (fit without sanding)
- [ ] Separate component; features grouped on the timeline
- [ ] Timeline: components → joints (including under `PRINT_LAYOUT`)
- [ ] Servo Configurator: no errors/warnings for any predefined servo
- [ ] Copy (not Paste New) under `PRINT_LAYOUT`, origin joint, print orientation
- [ ] Placed in the correct same-color `PartsSet*` with a joint; bed footprint kept reasonable
- [ ] Parts Exporter export for all servos; `.f3d` + exports committed
- [ ] Docs synced (README parts table / order-parts / assembly as needed)
- [ ] `AiEmblem` not repurposed as branding
- [ ] CERN-OHL-S respected; NOTICE Source Location accurate if distributing Products
- [ ] Optional/mod work under `mods/<mod_name>/3d_models/{cad,parts}/` (+ mod README)

## Related

| Topic | Doc |
| --- | --- |
| Servo params, add-in install, new servo preset | [parametric-design.md](parametric-design.md) |
| Print / part inventory | [`3d_models/README.md`](../../3d_models/README.md) |
| Optional mods folder | [`mods/README.md`](../../mods/README.md) |
| Order aggregated sets | [order-parts.md](order-parts.md) |
| Mechanical assembly | [assembly.md](assembly.md) |
| Trademark | [TRADEMARK.md](../../TRADEMARK.md) |
| Contribute / licenses | [CONTRIBUTING.md](../../CONTRIBUTING.md) |

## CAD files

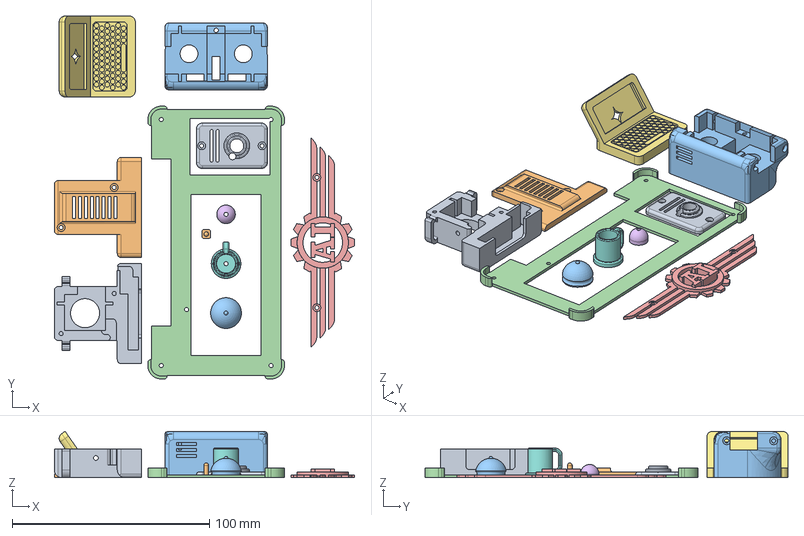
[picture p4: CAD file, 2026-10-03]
3d_models/parts/fs0307/step/PartsSetA.step
152.2 x 183.8 x 23.5 mm

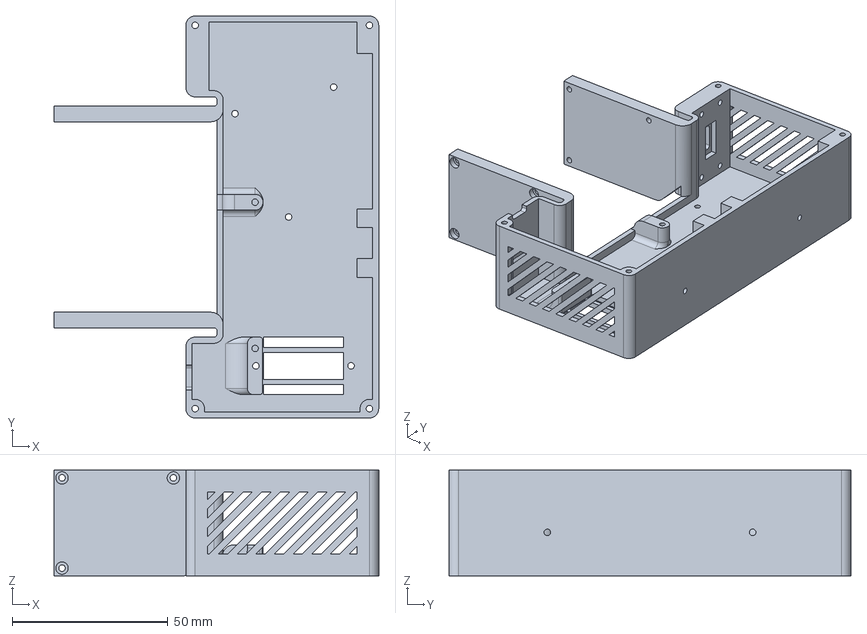
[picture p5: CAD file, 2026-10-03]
3d_models/parts/hd1370a/step/Desk.step
104.3 x 129.2 x 34.0 mm

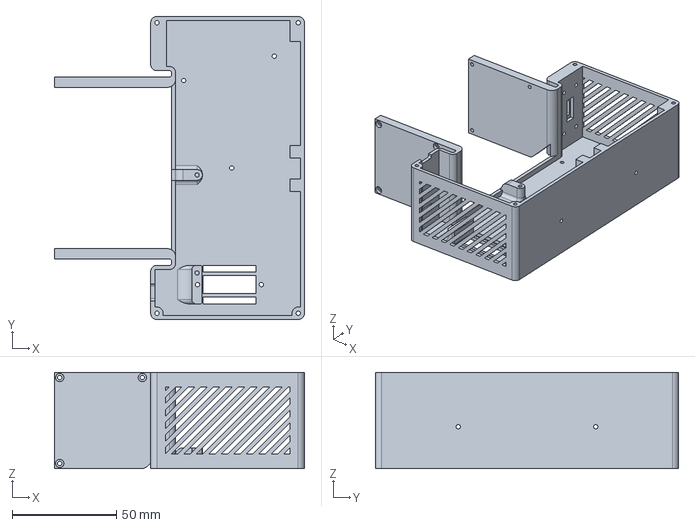
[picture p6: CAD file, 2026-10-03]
3d_models/parts/sg90/step/Desk.step
120.0 x 145.4 x 46.2 mm

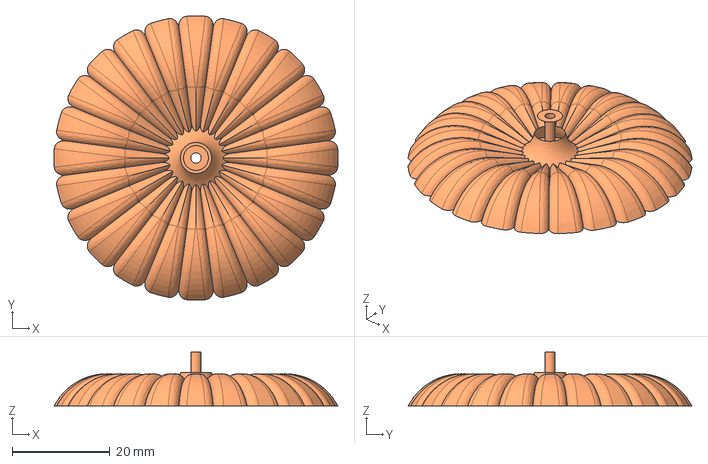
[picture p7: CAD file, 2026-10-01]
mods/halloween/3d_models/parts/fs0307/step/PumpkinTop.step
58.1 x 58.1 x 11.0 mm

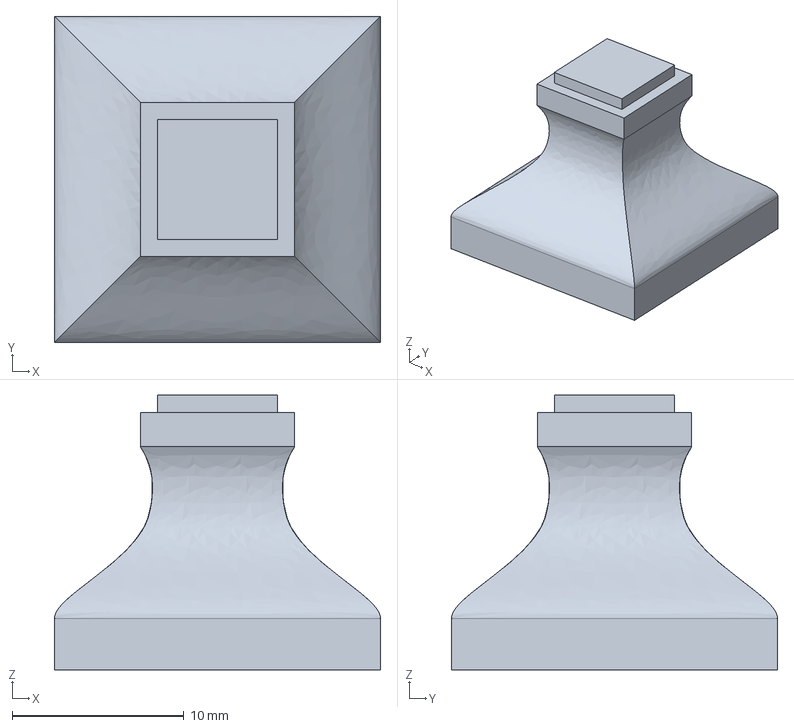
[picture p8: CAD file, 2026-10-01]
mods/halloween/3d_models/parts/hd1370a/step/LampCap.step
19.0 x 19.0 x 16.0 mm

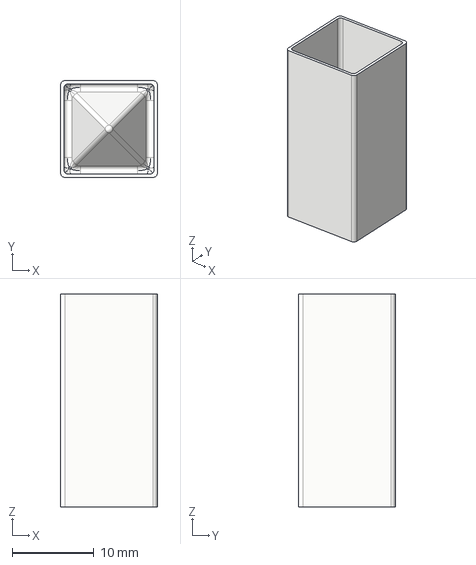
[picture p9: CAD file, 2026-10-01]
mods/halloween/3d_models/parts/sg90/step/LampDiffuser.step
11.8 x 11.8 x 26.0 mm

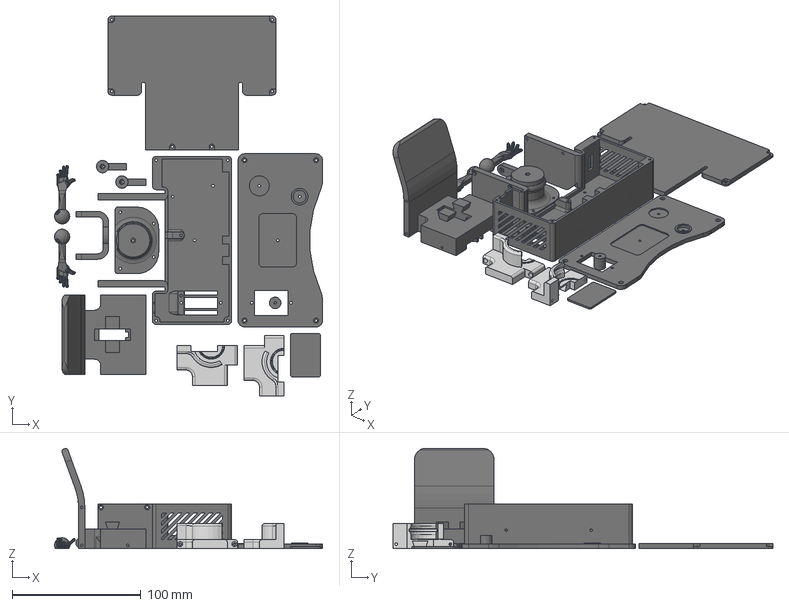
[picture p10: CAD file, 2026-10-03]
3d_models/parts/fs0307/step/PartsSetB.step
208.3 x 295.2 x 77.8 mm

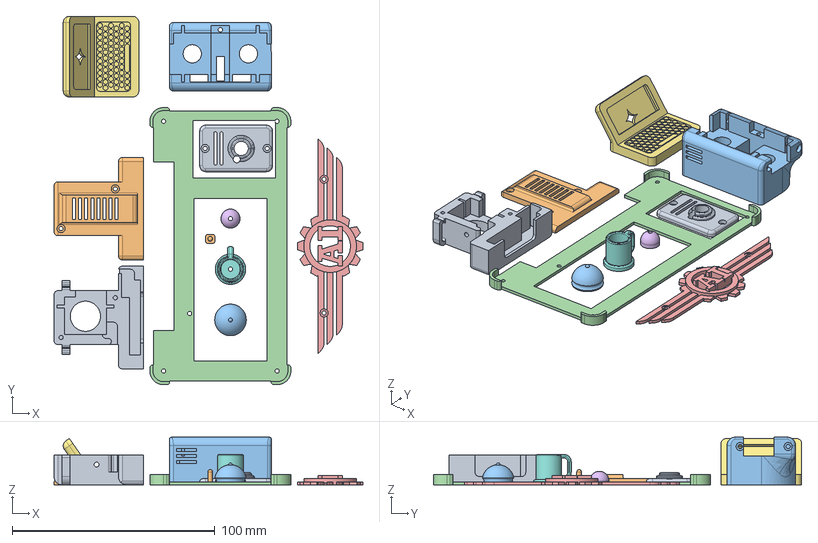
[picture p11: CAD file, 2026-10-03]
3d_models/parts/hd1370a/step/PartsSetA.step
152.5 x 181.8 x 23.5 mm

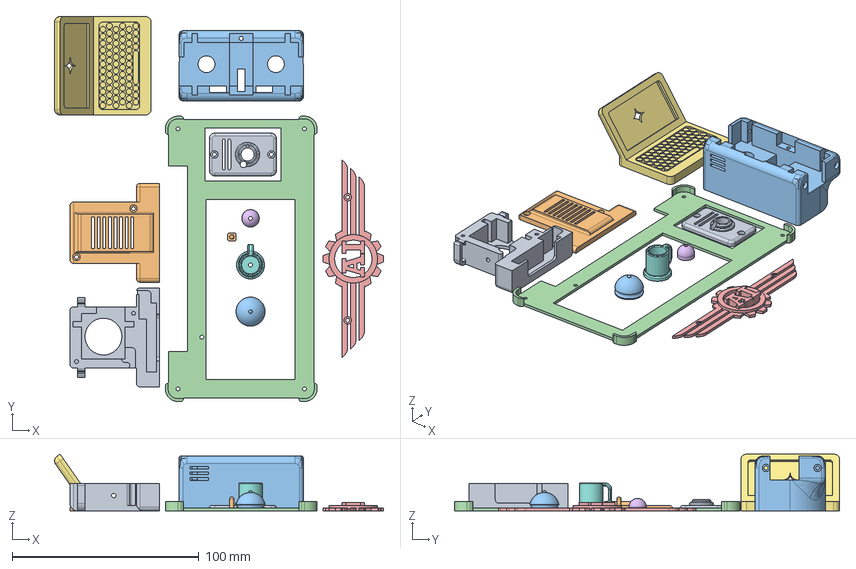
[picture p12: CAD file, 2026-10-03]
3d_models/parts/sg90/step/PartsSetA.step
176.4 x 206.4 x 30.4 mm

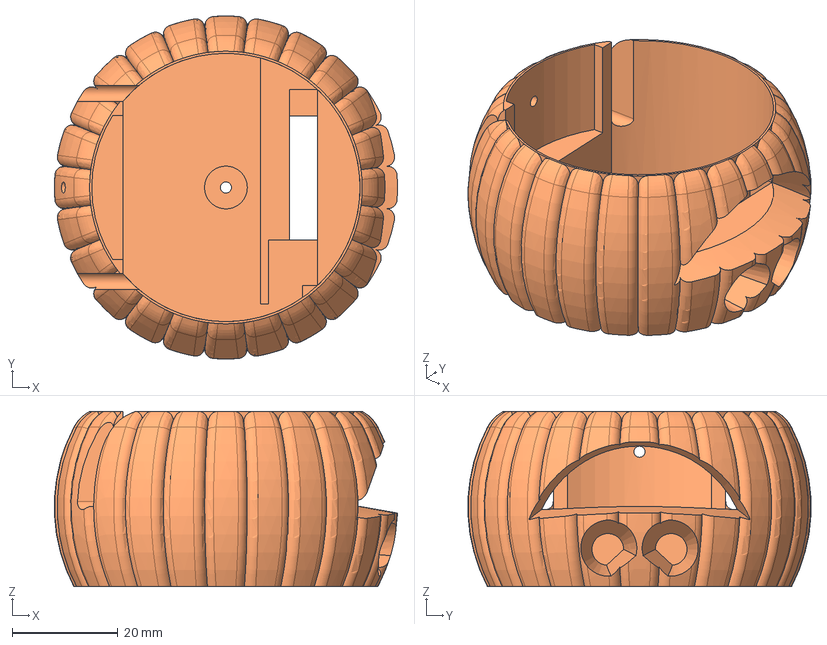
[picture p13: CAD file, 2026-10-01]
mods/halloween/3d_models/parts/hd1370a/step/PumpkinCover.step
65.0 x 65.0 x 33.2 mm

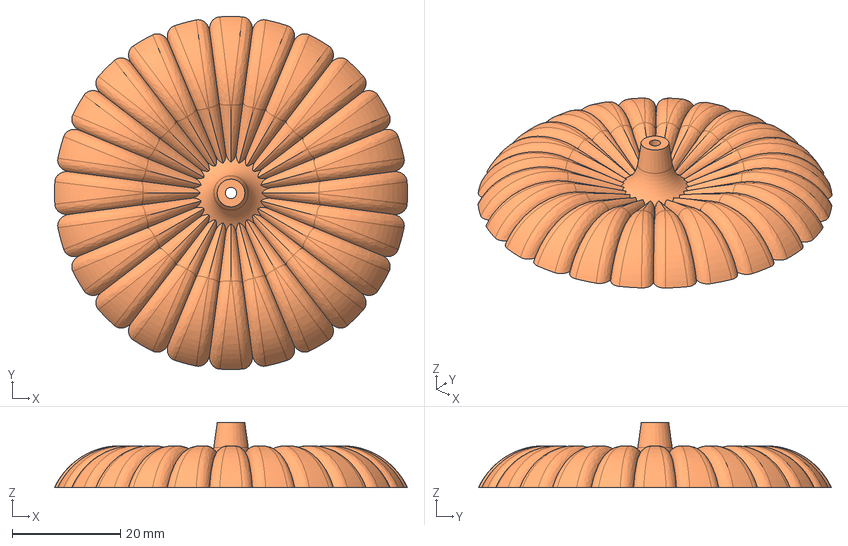
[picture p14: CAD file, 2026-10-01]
mods/halloween/3d_models/parts/sg90/step/PumpkinTop.step
65.2 x 65.2 x 12.0 mm

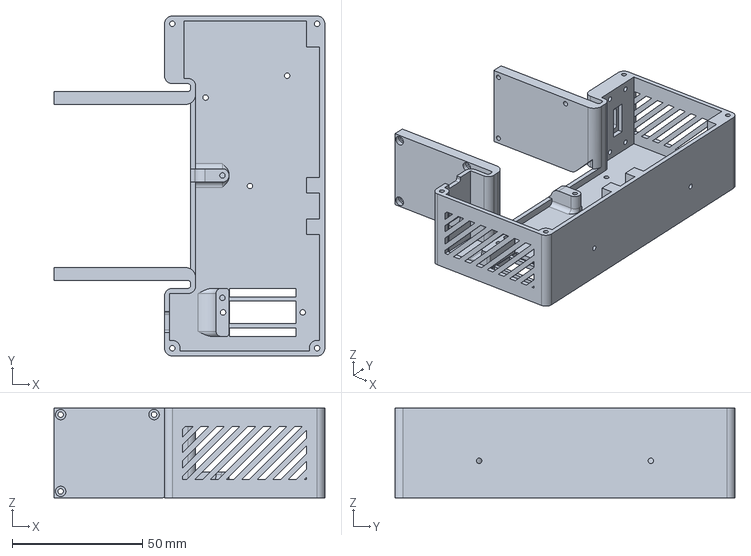
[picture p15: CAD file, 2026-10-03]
3d_models/parts/fs0307/step/Desk.step
104.0 x 130.6 x 34.5 mm

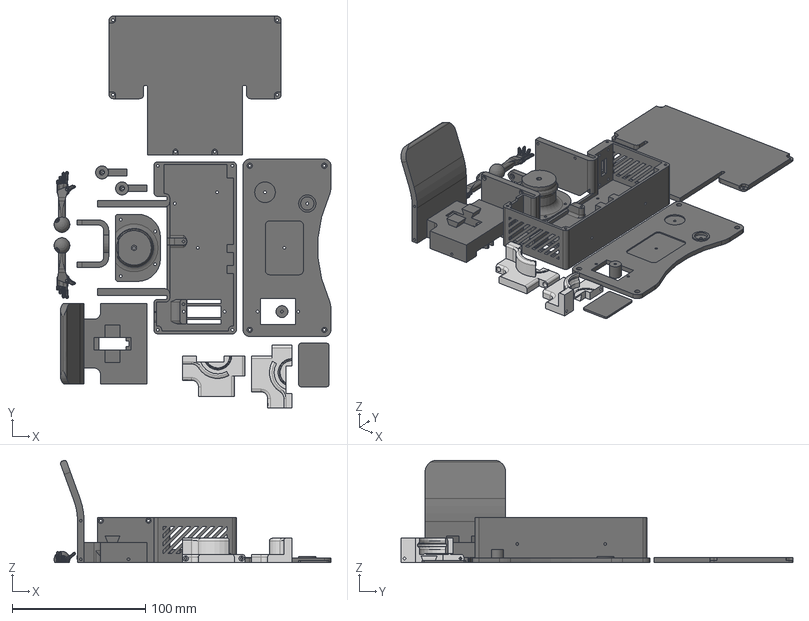
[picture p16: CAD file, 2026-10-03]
3d_models/parts/hd1370a/step/PartsSetB.step
207.9 x 294.0 x 76.8 mm

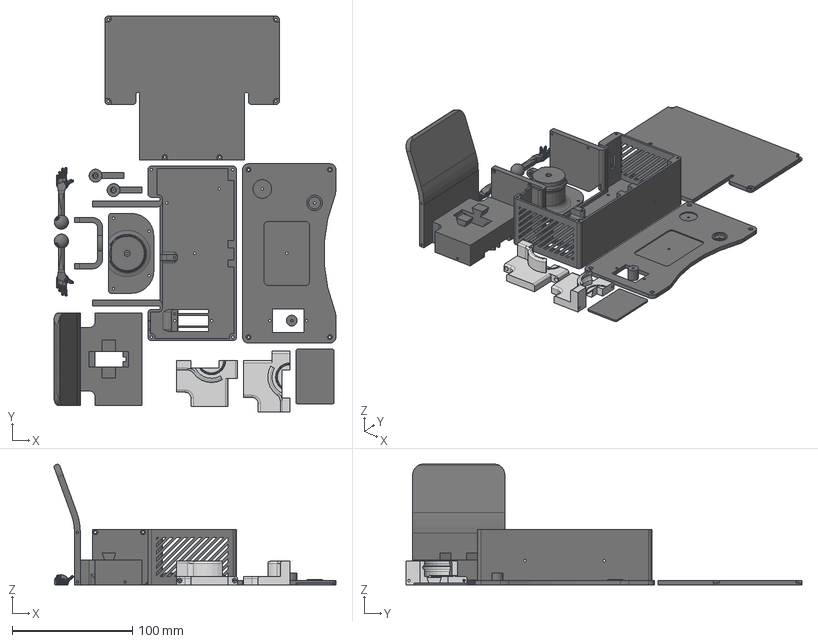
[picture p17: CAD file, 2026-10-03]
3d_models/parts/sg90/step/PartsSetB.step
234.7 x 329.7 x 100.4 mm

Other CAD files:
mods/halloween/3d_models/parts/fs0307/step/LampCap.step
mods/halloween/3d_models/parts/fs0307/step/LampDiffuser.step
mods/halloween/3d_models/parts/hd1370a/step/LampDiffuser.step
mods/halloween/3d_models/parts/sg90/step/LampBase.step
3d_models/cad/TinyEngineer.f3d
3d_models/parts/fs0307/3mf/AiEmblem.3mf
3d_models/parts/fs0307/3mf/Bell.3mf
3d_models/parts/fs0307/3mf/Belly.3mf
3d_models/parts/fs0307/3mf/BottomCover.3mf
3d_models/parts/fs0307/3mf/Chair.3mf
3d_models/parts/fs0307/3mf/Chest.3mf
3d_models/parts/fs0307/3mf/Coffee.3mf
3d_models/parts/fs0307/3mf/Desk.3mf
3d_models/parts/fs0307/3mf/DeskPad.3mf
3d_models/parts/fs0307/3mf/DeskTop.3mf
3d_models/parts/fs0307/3mf/ForearmLeft.3mf
3d_models/parts/fs0307/3mf/ForearmRight.3mf
3d_models/parts/fs0307/3mf/Hat.3mf
3d_models/parts/fs0307/3mf/Head.3mf
3d_models/parts/fs0307/3mf/LampBase.3mf
3d_models/parts/fs0307/3mf/LampButton.3mf
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

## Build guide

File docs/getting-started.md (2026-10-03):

# Getting started

Canonical build checklist for Tiny Engineer. Each step: open the linked doc, finish the exit criterion, return here. Mechanical joins live in [assembly.md](3d/assembly.md); this page owns overall order.

Robot already on Wi-Fi? Jump to [step 8](#8-agent-hooks).

## Safety

Read this before you power anything. Optional primer, not a gate: [From Code to Circuits](hardware-for-software-engineers/README.md).

- Supply **5 V / ≥2 A** on the board USB-C.
- Speaker: connector **or** solder pads, never both. **SPK− is not ground.**
- Leave the C3-Zero ceramic antenna clear of metal and dense plastic.

## Timeline

Shop → print → connect → flash → assemble (one run) → setup wizard → prove → agent hooks.

The default build uses the **main control board**. Plug in the ESP32, OLED, servos, and speaker. To add modules the board does not carry, follow the harness rules in [wiring.md](hardware/wiring.md) and mount them with [assembly-modular.md](3d/assembly-modular.md).

```mermaid
flowchart LR
  shop[Shop]
  print[Print]
  connect[Connect]
  flash[Flash]
  mech[Assemble]
  wiz[Wizard]
  prove[Prove]
  agent[Agent]

  shop --> print --> connect --> flash --> mech --> wiz --> prove --> agent
```

## Checklist

### 1. Shop

- **Open:** [shopping.md](shopping.md). Default cart is the main control board plus the ESP32, OLED, servos, and speaker.
- **Until:** cart in hand — main control board, ESP32, servos, OLED, speaker, M2 screws/nuts, **5 V / ≥2 A** supply, **data** USB cable, and a print path (filament or a service order). Default servos: **Tower Pro SG90**.
- **Return** here.

### 2. Print or order

- **Open:** [3d_models/README.md](../3d_models/README.md) (home print; testers first) or [3d/order-parts.md](3d/order-parts.md) (no printer).
- **Until:** printed set for your servo model ready.
- **Return** here.

### 3. Connect

- **Open:** [hardware/main-control-board.md](hardware/main-control-board.md).
- **Until:** pre-power checks pass (speaker on **SPK+/SPK−** only, one method; servo plugs match the labels; ESP32 orientation matches the PCB USB mark). Electronics stay on the desk.
- **Advanced:** extra modules the board does not support — wire the harness now ([hardware/wiring.md](hardware/wiring.md)). Mount those boards during assembly ([3d/assembly-modular.md](3d/assembly-modular.md)).
- **Return** here.

### 4. Flash

- **Open:** [flash.md](flash.md).
- **Until:** firmware + LittleFS uploaded; serial boot OK; PCA9685 found; **Move all to 90°** or one `/test/servo` moves a channel. Do not finish the Wi-Fi wizard yet.
- **Return** here. Keep electronics on the desk — do not seat them in the chest yet.

### 5. Assemble

- **Open:** [3d/assembly.md](3d/assembly.md) from §1 through §19 (Head/Hat, centering, joins, channels, arms, lamp).
- **Until:** all joins done; servo and OLED headers plugged per the guide.
- **Return** here.

### 6. Setup wizard

- **Open:** [3d/assembly.md §20](3d/assembly.md#20-setup-wizard-and-first-boot-on-wi-fi).
- **Until:** wizard finished, power-cycled, robot on home **2.4 GHz** Wi-Fi.
- **Return** here.

### 7. Prove it

Open `http://tiny-engineer.local/` (or the IP on the OLED) for the web UI.

```bash
curl http://tiny-engineer.local/health
curl -X POST "http://tiny-engineer.local/anim?name=ring"
```

- **Until:** `/health` OK and `ring` runs (motion; sound if LittleFS uploaded). If `.local` is slow, use the OLED IP or `curl -4`.
- **Return** here. Full API: [api.md](api.md).

### 8. Agent hooks

- **Open:** [hooks.md](hooks.md) (Cursor) or [integration.md](integration.md) (Antigravity, Claude Code, raw REST).
- **Until:** optional — an agent event triggers an animation.
- Done.

## Stuck?

| Symptom | What to try |
| --- | --- |
| Extra modules the board does not support? | [shopping.md](shopping.md#advanced-extra-modules) · [hardware/wiring.md](hardware/wiring.md) |
| What to buy? | [shopping.md](shopping.md) |
| How to plug in the board? | [hardware/main-control-board.md](hardware/main-control-board.md) |
| What to print? | [3d_models/README.md](../3d_models/README.md) |
| How to assemble printed parts? | [3d/assembly.md](3d/assembly.md) |
| Flash / serial / LittleFS | [flash.md](flash.md) |
| `.local` slow or fails | OLED IP; `curl -4 http://…` |
| OLED shows join AP / `192.168.4.1` | Wi-Fi not saved or STA failed — finish [assembly §20](3d/assembly.md#20-setup-wizard-and-first-boot-on-wi-fi) |
| Welcome / ring silent (servos move) | LittleFS missing WAVs — `pio run -t uploadfs` ([flash.md](flash.md)) |
| Hooks never move the robot | Node 18+, hook `timeout` ≥ 30, HTTPS tarball `npx` — see [hooks.md](hooks.md) |
| Servos twitch / board resets on motion | Power budget — [hardware/power.md](hardware/power.md) |
| Other boot / I2C / audio failures | [hardware/testing.md](hardware/testing.md) |

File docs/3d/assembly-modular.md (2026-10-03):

# Modular assembly (advanced)

Mount breakout modules in the printed `Desk`. Use this when you add hardware the main control board does not support.

The default build seats the [main control board](../hardware/main-control-board.md) — follow [assembly.md](assembly.md) §12 and §13. This page replaces those two steps only. Electrical harness: [wiring.md](../hardware/wiring.md).

By this point the breakouts should already be wired and soldered as one harness, and firmware flashed ([flash.md](../flash.md)). Then return to [assembly §14](assembly.md#14-desk-props--laptop-mug-bell). Servo channel order is the same table in [assembly §15](assembly.md#15-connect-servos-and-oled); plug the leads into the PCA9685 instead of the board headers.

## Electronics inside the desk

**Leave disconnected for now:**

- ESP32 — attach the gold-pin jumper cables to the ESP32 pins in the next section
- PCA9685 — plug servo connectors in [assembly §15](assembly.md#15-connect-servos-and-oled)

Everything else in the harness stays as already soldered and assembled.

1. **USB-C breakout (Adafruit 5993)** — fasten with four longer M2 screws (M2×16 mm works) and secure with M2 nuts.
2. **PCA9685** — fasten to the rails on the inside of the desk front with four short M2 screws (M2×4 mm works).
3. **MAX98357A** — mount on the single rail on that same inner front wall with two M2 screws (M2×4 mm works).
4. **Speaker** — stick it to an inner wall, or leave it loose inside the desk for now.

Mount in that order — USB first, then PCA9685, then MAX98357A, then the speaker — so later boards are not in the way.

Desk

## ESP32, power/AP smoke test, and `LampBase`

1. Seat the **ESP32-C3-Zero** in the opening in the desk top from above. The pins must pass through the holes in the top; the module should sit flush in the recess and not stick up above the desk surface.
2. From underneath, connect the gold-pin jumper cables to the ESP32.
3. **Power/AP smoke test** (optional but recommended) before locking the module in:
   - Confirm every wire is on the correct pin ([wiring](../hardware/wiring.md)). Servo plugs and the OLED come later.
   - Firmware should already be on the board (flashed before servo centering).
   - Apply power. The ESP32 LED should light and the board should start the **setup access point** for configuration.
   - If that looks good, **disconnect power**.
4. Place the printed `LampButton` under `LampBase` so it can press the ESP32 **reset** button from above — keep that access easy.
5. Orient `LampBase` so its opening sits over the ESP32 status LED.
6. Fasten `LampBase` to the desk with **two M2 screws** (M2×8 mm works). This also holds the ESP32 from above.

Desk

## Next

Continue at [assembly §14](assembly.md#14-desk-props--laptop-mug-bell).

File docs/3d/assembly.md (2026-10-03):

# Mechanical assembly

How to join the printed parts and seat the five micro servos. Use **M2 screws** that thread into the plastic — no glue, no heat-set inserts.

Follow [getting-started.md](../getting-started.md) for overall build order; this file is the mechanical procedure. Start here **after** connecting and flashing.

Screw lengths called out below (M2×4 / ×8 / ×16) match the reference list. If you substitute nearby lengths, **test-fit** first. Totals: [3d_models/README.md → Screws](../../3d_models/README.md#screws). Buyer cart: [shopping.md](../shopping.md).

**Before you start:** the main control board is connected on the desk and firmware is flashed ([main-control-board.md](../hardware/main-control-board.md), then [flash.md](../flash.md)). Print or order the set for your servo model ([3d_models/README.md](../../3d_models/README.md), [order-parts.md](order-parts.md)). All five servos are the same type; the printed pockets match that model. Breakout modules: [assembly-modular.md](assembly-modular.md) replaces §12 and §13 below.

**Left / right:** throughout this guide, “robot’s left” and “robot’s right” mean the **figure’s** sides — not your left/right as you face it.

### Build map

1. Head + Hat (OLED + head servo)
2. Center Neck → join Head/Neck → Chest side servos → mount on Chest → Belly → Chair
3. Desk stack → mount electronics → plug channels → Chair↔Desk → BottomCover
4. Arms → Lamp → setup wizard

## 1. Head — OLED and servo

1. Peel the protective sticker off the Waveshare OLED screen.
2. Plug the cable that shipped with the Waveshare OLED into the display **before** seating it. Once the OLED is in its pocket, the connector is hard to reach.
3. Take one of the five identical micro servos. Do **not** attach a horn yet. Orientation does not matter at this stage.
4. Seat the servo and the OLED into their dedicated pockets in the printed `Head`.
5. Route both cables through the openings in the shell — OLED cable on one side of the head, servo lead on the opposite side.
6. Clip each cable into the molded cable clips on the **back** of `Head` (clips are part of the print).

Head

## 2. Hat

1. Place `Hat` on top of `Head`.
2. Fasten with **two M2 screws** (M2×8 mm works). Thread into the printed plastic — do not overtighten.

Head

## 2a. Bench window (centering)

Electronics and firmware should already be done ([getting-started](../getting-started.md) connect + flash). If the module is not flashed yet, stop and do [flash.md](../flash.md) first. From here on you set each printed part on a servo that is already at **90°** (shaft center).

**Bench window:** keep the electronics on the desk — do **not** seat them in the chest until [§12](#12-electronics-inside-the-desk).

> **Stop.** Join the setup AP only to press **Move all to 90°**. Do **not** finish the wizard (ranges, OLED, LED, speaker, home Wi-Fi) until [§20](#20-setup-wizard-and-first-boot-on-wi-fi).

After each centering step, **unplug the servo from the PCA9685** before you keep building. Leaving the lead attached makes the next joins awkward. You reconnect the correct channels later.

### Center a servo

Use this recipe whenever a later step says to center a servo:

1. Plug the servo into any PCA9685 channel (channel mapping does not matter for centering).
2. Power the ESP32. Join the setup Wi‑Fi (`TinyEngineer-XXXX`), open `http://192.168.4.1/config`, and press **Move all to 90°**. The shaft is now at electrical center.
3. After you finish that joint, **unplug** the servo from the PCA9685 before the next awkward join.

## 3. Neck — center a servo and attach `Neck`

1. Take the **next** unused servo (not the one already in `Head`). Do **not** attach a plastic horn — `Neck` mounts on the shaft.
2. [Center that servo](#center-a-servo).
3. Press `Neck` onto the servo shaft so the part sits **perpendicular** to the servo body.
4. Align the raised bulge in the middle of `Neck` toward the **back** of the servo — the longer end of the servo body (cable / electronics side).
5. Fasten `Neck` with the **screw that came with the servo**, keeping that perpendicular orientation.
6. Drop an **M2 nut** into a hexagonal pocket on `Neck`:
   - Use the pocket with the **larger** center hole.
   - That pocket is on the **robot’s right**.
   - The pocket with the smaller hole is for mounting a servo later — leave it empty for now.
7. Unplug this servo from the PCA9685 so the next steps are easier to handle.

Neck

## 4. Join `Neck` and `Head`

1. [Center](#center-a-servo) the servo already inside `Head`.
2. Take the `Neck` assembly from §3. **First stage:** fit `Neck` onto the Head servo shaft — `Neck` has a dedicated pocket for that shaft. Gently push the Head cables aside if needed so the shaft seats fully.
3. **Second stage:** slide `Neck` further onto `Head` until the side with the M2 nut sits flush with `Head` and lines up with the mounting hole on that side. Keep the nut in its hex pocket so it does not fall out.
4. At 90°, `Neck` must sit **perpendicular** to `Head`. Adjust before fastening if needed.
5. Fasten `Neck` to `Head`:
   - Robot’s right: M2 screw into the captured nut (M2×8 mm works).
   - Robot’s left: the mounting screw that came with the servo.
6. Unplug the Head servo from the PCA9685 before continuing.

Neck

## 5. Chest — side servos

1. Take the printed `Chest`.
2. Seat **two** unused servos in the side pockets (left and right). No horns yet. Shaft orientation does not matter — you will calibrate later.
3. Route each servo lead through the **vertical tunnel at the front** of `Chest` so the connectors exit from the **bottom** of the part.
4. Fasten both servos with **four M2 screws** total — two per servo (M2×16 mm works). Do not overtighten.

Chest

## 6. Mount head assembly on `Chest`

1. Take the joined `Head` + `Neck` from [§4](#4-join-neck-and-head). The servo already fastened to `Neck` goes into the **center** servo pocket in `Chest`.
2. **Before** seating that servo, route its lead through the **central tunnel** in `Chest` and out the **bottom** of the part.
3. Seat the Neck servo fully in the center pocket. Keep front of `Head`/`Neck` on the same side as front of `Chest` (the side with the cable tunnels).
4. Fasten it to `Chest` with M2×8 mm screws. Prefer two screws; if space is tight, one screw at the back of the robot is enough.

Chest

## 7. Belly — last servo

1. Take the **last** unused servo. [Center it](#center-a-servo).
2. Press `Belly` onto the servo shaft — `Belly` has a dedicated pocket for the shaft. Do **not** use a plastic horn.
3. Orient the servo **perpendicular** to `Belly`, with the longer end of the servo body toward the **rounded** side of `Belly`.
4. When alignment is correct, fasten with the **screw that came with the servo**.
5. Unplug this servo from the PCA9685 before continuing.

Belly

## 8. Route chest cables through `Belly` and join

1. Take the three servo leads that exit the bottom of `Chest`: Neck (center) and the two side (hand) servos.
2. Pass them into `Belly` through the **large upper** opening, then out through the **lower side** opening.
3. Keep the same left-to-right order as they leave `Chest`: **left hand → neck → right hand**. That order is only an identification aid for later — not the PCA9685 channel sequence.
4. Orient `Belly` so its rounded side faces the **back** and matches the profile of `Chest`, then fasten with **four M2 screws** (M2×8 mm works).

Belly

## 9. Seat the body in `Chair`

1. Take the robot body (`Head` through `Belly`). The servo already fastened to `Belly` goes into the dedicated pocket in `Chair`.
2. Orient so the front of the robot matches the front of the chair (the way the figure sits).
3. Route that servo’s lead through the **vertical tunnel** in `Chair` and out under the chair.
4. Slide `SeatLeft` and `SeatRight` in from the sides onto the rails / pockets on `Chair`. The seats lock the body servo in place so it cannot drop out of `Chair`. Watch the cables — do not pinch or crush them while seating the parts.
5. Fasten the two seat parts to each other with **two M2 screws** (M2×16 mm works).

This finishes the **main robot body**. Set it aside — next steps build the desk.

Chair

## 10. Desk top stack

1. Take `DeskTop`, `DeskPad`, and `Desk`.
2. Seat `DeskTop` into `DeskPad` — the parts nest together.
3. Place that stack onto `Desk`. Orient so the rounded cutout faces the robot (the side where the figure sits).
4. Fasten through the four corner holes with **four M2 screws** (M2×16 mm works).

Desk

## 11. Desk emblem

1. Place `AiEmblem` on the front of the desk.
2. Fasten with **two short M2 screws** (M2×4 mm works).

Desk

## 12. Electronics inside the desk

Seat the **main control board** in `Desk`. This step mounts what you already connected on the desk ([getting-started](../getting-started.md) connect + flash). Electrical plugs: [main-control-board.md](../hardware/main-control-board.md). Breakout modules: [assembly-modular.md](assembly-modular.md).

1. Seat the board in the desk cavity.
2. Leave servos and the OLED unplugged until [§15](#15-connect-servos-and-oled).
3. **Speaker** — finish the board connector or the solder pads per the connect guide (one method only). Stick or tuck the speaker inside the desk as needed.
4. Leave the ESP32 out until [§13](#13-esp32-powerap-smoke-test-and-lampbase) — it seats from above into the board headers through the desk-top cut.

## 13. ESP32, power/AP smoke test, and `LampBase`

1. Seat the **ESP32-C3-Zero** in the desk-top opening from above so its pins pass through the cut **into the board headers** underneath. Orient using the **USB** marking on the PCB ([main-control-board.md](../hardware/main-control-board.md)). The module should sit flush and not stick up above the desk surface.
2. **Power/AP smoke test** (optional but recommended) before locking the module in:
   - Confirm seating and orientation. Servo plugs and the OLED come in [§15](#15-connect-servos-and-oled).
   - Firmware should already be on the module.
   - Apply power on the **board USB-C**. The ESP32 LED should light and the board should start the **setup access point**.
   - If that looks good, **disconnect power**.
3. Place the printed `LampButton` under `LampBase` so it can press the ESP32 **reset** button from above.
4. Orient `LampBase` so its opening sits over the ESP32 status LED.
5. Fasten `LampBase` to the desk with **two M2 screws** (M2×8 mm works). This also holds the ESP32 from above.

## 14. Desk props — laptop, mug, bell

1. **Laptop** — slide `LaptopScreen` into the pocket on the underside of `LaptopCase`. Place the laptop on the desk and fasten with one M2 screw from under the desk (M2×8 mm works).
2. **Mug** — seat `Coffee` inside `Mug`. Place the mug in its dedicated spot on the desk and fasten the same way: one M2 screw from under the desk (M2×8 mm works).
3. **Bell** — first drive the M2 screw fully into `Bell` alone (M2×16 mm works). Then, with the screw already in the bell, drive that screw down into the desk from above and secure with an M2 nut underneath.

Desk

## 15. Connect servos and OLED

Easiest with the desk tipped onto its front wall so the servo headers face up, and the seated robot body beside it.

1. Plug every servo lead and the OLED cable into the labeled board headers ([main-control-board.md](../hardware/main-control-board.md)). Breakout build: plug them into the PCA9685 and the harness — [assembly-modular.md](assembly-modular.md).
2. Use the correct PCA9685 channel order ([pinout](../hardware/pinout.md#pca9685-channels-not-esp32-gpio)):

   | Channel | Joint |
   | --- | --- |
   | 0 | Head pitch |
   | 1 | Neck yaw |
   | 2 | Left hand |
   | 3 | Right hand |
   | 4 | Body / torso |

   The left-to-right order through `Belly` is only an ID aid — **not** the channel sequence. Map explicitly:

   | Lead (as routed through Belly) | Channel |
   | --- | --- |
   | Left hand | 2 |
   | Neck | 1 |
   | Right hand | 3 |

   Head pitch → channel **0**. Body / torso (Belly servo under the chair) → channel **4**.
3. Power up and run a **servos + OLED smoke test**: servos respond, OLED shows something sensible, no brown-out or odd movement. If something is wrong, power down before swapping plugs.

Desk

## 16. Fasten `Chair` to `Desk`

1. Gently slide the desk up to the chair so the mounting holes on the desk (back / armrest sides) line up with the matching holes on `Chair`.
2. Fasten with **six M2 screws** total — three per side (M2×8 mm works). Do not force the parts; keep cables clear of the screw paths.

Desk

### Close the underside with `BottomCover`

1. Finish the servo and OLED cables and the six side screws joining `Chair` to `Desk` first. Power down, support the robot, and turn it over without loading the arms or desk props.
2. Route the chair leads through the existing tunnel and into the desk cavity. Keep the cables inside the perimeter, away from all six cover screw paths; no wire should sit between the cover and the chair/desk mating surfaces.
3. Use the updated `Chair` from the same servo folder: it has two reinforced blind pilot holes underneath its rear wall. An older chair without these holes must be reprinted for the six-point attachment; keep clear of the existing side screws and cables.
4. Place the flat mating face of `BottomCover` against the desk and chair. Its stem follows the chair; the recessed pockets face outward. Align the four desk holes and the two rear chair holes.
5. Fasten with **six M2×8 mm** pan/button-head screws — four into the desk and two into the chair. Heads no larger than **4.0 mm diameter × 2.0 mm high**. No nuts.
6. Tighten until each head sits in its pocket and none sticks past the flat underside. No trapped wires. Set the robot upright.

Print `BottomCover` with its **mating face down and pockets up**, as exported. No supports. Printed fit still needs a test-fit.

## 17. Arms — elbow joints

Build the arm assemblies only — do **not** mount them on the chest servos yet.

1. At each elbow there is a screw hole joining the forearm to the upper arm.
2. Fasten left and right the same way: `ForearmLeft` to `UpperArm` and `ForearmRight` to `UpperArm` with one M2 screw per elbow (M2×8 mm works). Print / use two `UpperArm` parts (one per side).

Arms

## 18. Mount arms on the chest servos

1. [Center](#center-a-servo) the side (hand) servos first.
2. Press each arm assembly onto its chest servo shaft. The upper arms have dedicated pockets for the shafts.
3. With the servos at 90°, set each arm so the hand sits at about shoulder height and the forearm points forward (toward the desk).
4. When the pose looks right, fasten each arm with the mounting screw that came with that servo.
5. Do this for both arms. If centering is not perfect, that is fine — you will refine it in the setup calibration later.

Body

## 19. Lamp (press-fit)

No screws — everything is a friction fit.

1. Place `LampCap` onto `LampDiffuser`.
2. Push that stack into the opening in `LampBase`.

Lamp

## 20. Setup wizard and first boot on Wi-Fi

The robot is built. What remains is servo calibration, Wi-Fi, and a quick check that everything works.

1. Connect power. The board should start the **setup access point** (`TinyEngineer-XXXX`). First boot, or after factory reset + power-cycle.
2. Join that Wi-Fi and open the configurator (`http://192.168.4.1/config`).
3. Walk through the **entire setup wizard**:
   1. Seat printed parts on the servo shafts at 90°, then mark each joint’s safe min/max (factory reset keeps prior ranges; you can still change them here).
   2. Look at the OLED and tap Rotate 180° if text is upside down (factory reset keeps the rotation).
   3. Tap Red/Green/Blue on the onboard LED; change mapping only if colors look wrong (default **GRB**; factory reset keeps the mapping).
   4. Play the welcome clip through the speaker.
   5. Hostname and home Wi-Fi (**2.4 GHz** only). OLED shows join-AP steps.
4. When the wizard is finished, **disconnect power**, then power on again.
5. The robot should join your home network and expose the **REST API**. Prove it — [getting-started §7](../getting-started.md#7-prove-it), [api.md](../api.md).

Wi-Fi is not editable from the normal Config page later — factory reset to change it.

## Related

| Topic | Doc |
| --- | --- |
| Overall build checklist | [getting-started.md](../getting-started.md) (assemble is [§5](../getting-started.md#5-assemble)) |
| Shopping list | [shopping.md](../shopping.md) |
| Parts inventory / printables | [3d_models/README.md](../../3d_models/README.md) |
| Print or order parts | [getting-started §2](../getting-started.md#2-print-or-order) · [order-parts.md](order-parts.md) |
| Different servo size / CAD params | [parametric-design.md](parametric-design.md) |
| Servo axes and safe ranges | [robot-movement.md](../robot-movement.md) |
| Connect and flash (before this page) | [hardware/main-control-board.md](../hardware/main-control-board.md) · [flash.md](../flash.md) |
| Extra modules (advanced) | [assembly-modular.md](assembly-modular.md) · [hardware/wiring.md](../hardware/wiring.md) |

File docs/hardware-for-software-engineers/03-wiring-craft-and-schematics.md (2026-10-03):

# Wiring craft and schematics

Software has stack traces. Hardware has smoke. Most beginner failures aren't mysterious — they're a loose GND, swapped data lines, or a wire that pulled out when you closed the case. This chapter is about making connections you can trust and reading the diagram — Tiny Engineer's drawing is the practice artifact.

---

## Dupont / jumper — the connector this project uses

**Dupont** (jumper) = plastic housing on a pin header. One wire, one pin. That's the whole connector story here.

This build uses Dupont on **servos**, **OLED**, and **ESP32** so those parts unplug and swap if something dies. Servo cables already end in a 3-pin plug (signal / +5 V / GND — often yellow, red, brown; **verify your batch**). That plug seats on Dupont-style headers.

> **If you've written backend code…** Dupont is like a typed port: one pin, one job. Read the silkscreen. Wrong hole is a type error with smoke.

---

## Breadboard vs permanent wiring

**Breadboard** — spring clips, no solder. Great for blinking an LED. Wires pop out. Too bulky for this robot.

The default build plugs the ESP32, OLED, servos, and speaker into the [main control board](../hardware/main-control-board.md). The soldered harness below is the **advanced** path — extra modules the board does not support ([wiring.md](../hardware/wiring.md), [shopping](../shopping.md#advanced-extra-modules)). Those joints have to survive a small printed body. Vibration and tight space kill breadboard builds.

**Practical split (modular):**
- **Solder** the boards that stay in the robot: USB-C breakout, PCA9685 servo driver, audio amp, and the power/signal harness between them
- **Dupont** to ESP32, OLED, and servos — replaceable without a soldering iron
- Wire and **verify on the desk** (boot, I2C, one servo) **before** seating the electronics in the chest. Debugging inside a closed chest is miserable

The Waveshare **ESP32-C3-Zero** used here ships with **male pins already soldered**. On the modular path you still solder everything else that doesn't come with headers you can plug into: USB socket/breakout, servo controller, audio board, and the wires that join those modules.

---

## Strain relief and color

Don't tug on solder joints. Zip-tie or clip USB and servo cables so a yank hits the tie, not the pad.

Color is habit, not law: red ≈ positive, black/brown ≈ GND, yellow/orange/green ≈ signal. **Trust labels and a multimeter, not memory.**

---

## Reading schematics and block diagrams

You don't need a full EE schematic. You need the **block diagram** mindset:

- **Boxes** = modules (ESP32, PCA9685, OLED, amp)
- **Lines** = nets (SDA, SCL, 5V, GND)
- **Same net name** = must be connected together

Tiny Engineer's map: [Tiny Engineer.drawio.png](../wiring/Tiny%20Engineer.drawio.png).

> **If you've written backend code…** The PNG is an architecture diagram. [wiring.md](../hardware/wiring.md) is the connection table. [pinout.md](../hardware/pinout.md) is GPIO allocation. Same system, three views.

**How to use the diagram:**
1. Find the ESP32 box — trace I2C to PCA9685 and OLED
2. Trace 5 V from USB breakout to each power consumer
3. Trace 3.3 V from ESP32 to logic VCC pins
4. Confirm GND stars at the USB breakout and fans out

Don't memorize — **trace the path** for whatever you're debugging.

---

## Soldering: enough to not fear it

You will solder. The ESP32 headers are already done; USB, PCA9685, audio, and the interconnects are not.

Basics:
- **Iron** ~350°C for lead-free (follow your solder's label)
- **Tin the pad and the wire**, then join — don't dump a blob on one side
- **Continuity check** after — multimeter beep between pad and wire end

Bad solder looks dull and grainy (cold joint). Good joint is shiny and concave. YouTube "through-hole soldering" beats a paragraph here.

---

## What not to do on first power-up

- Don't power servos before common GND is verified
- Don't connect MAX98357A **SPK−** to GND (bridge-tied load — see [Ch. 04](04-buses-and-protocols.md))
- Don't force a tight 3D-printed pocket onto a servo — ream or reprint instead

Assembly checks before first power: [main-control-board.md](../hardware/main-control-board.md). Advanced harness: [wiring.md](../hardware/wiring.md) — read that when you're actually wiring, not this chapter.

---

## In Tiny Engineer

The default connect checklist is [main-control-board.md](../hardware/main-control-board.md). The drawio and the steps below are the advanced breakout harness: [Tiny Engineer.drawio.png](../wiring/Tiny%20Engineer.drawio.png) and [wiring.md](../hardware/wiring.md). This guide doesn't duplicate the connection table.

**Desk smoke order** (wiring mindset — after wire + flash, before the mechanical run):
1. USB power + GND only → ESP32 boots (LED, serial)
2. Add I2C devices → serial shows PCA9685 found
3. Add one servo on one channel → `/test/servo` or setup AP **Move all to 90°**
4. Add audio and OLED as you wire the rest of the harness
5. Then open [assembly.md](../3d/assembly.md) from §1 (one mechanical run). Seat the harness with [assembly-modular.md](../3d/assembly-modular.md), which replaces assembly §12–§13.

**OLED naming trap:** this build uses the [Waveshare 0.91inch OLED Module](https://www.waveshare.com/0.91inch-oled-module.htm), which labels the clock pad **SCL**. Many clone 0.91" boards print **SCK** on that same I2C clock pin — not SPI. The wiring PNG may still say **SCK**.

---

**Next:** [Buses and protocols](04-buses-and-protocols.md)

**Reference:** [hardware/main-control-board.md](../hardware/main-control-board.md) · [hardware/wiring.md](../hardware/wiring.md) · [wiring/Tiny Engineer.drawio.png](../wiring/Tiny%20Engineer.drawio.png)

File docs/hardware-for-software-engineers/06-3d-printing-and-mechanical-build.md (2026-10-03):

# 3D printing and mechanical build

Software lives in repos; hardware lives in **enclosures**. 3D printing is how you turn CAD into a physical body — layer by layer, with tolerances that bite if you ignore them. If you've never printed, this chapter is the missing semester: materials, fit, CAD source, and not destroying a servo by forcing it into a tight pocket. **Tiny Engineer** is the case study; the skills transfer to any printed mount or case.

---

## FDM printing in 60 seconds

**FDM** (Fused Deposition Modeling) — the common hobby printer type — melts plastic filament layer by layer.

Knobs that matter:

| Parameter | Typical starting point | What it affects |
| --- | --- | --- |
| **Layer height** | **0.16 mm** (used for the tested prints) | Surface quality vs speed |
| **Infill** | 20–30% structural | Strength vs print time |
| **Orientation** | As in the `.3mf` | Overhangs; supports (see below) |
| **Material** | **PLA** is enough; PETG also works | Ease vs toughness |

### Supports

Plastic cannot print in mid-air. An **overhang** (a surface that sticks out with nothing under it) needs **supports** — extra throwaway plastic the slicer builds like scaffolding, then you snap or dissolve off.

Supports leave scars, use filament, and make small holes and servo pockets messy.

**This project's parts are designed and oriented so they print with no supports.** Keep the `.3mf` orientation. Rotate a part "to look nicer on the bed" and you may suddenly need supports and get ugly undersides.

### What printer

All parts were printed and test-fitted on a **Creality Ender 3 V3 SE**. You should be able to print them on **any FDM printer** that can run PLA (or PETG) at typical hobby settings — the files are not locked to that machine.

No printer? You can [order the aggregated part sets from a third-party service](../3d/order-parts.md) instead of printing at home, then continue with assembly.

---

## Materials: PLA vs PETG

**PLA is sufficient** for the whole robot — desk use, indoor, this design. **PETG also works** if that's what you have (tougher, a bit stringier to print). Pick one spool if you care about color match.

| Material | Use here |
| --- | --- |
| **PLA** | Default. Fine for servo pockets, chair, desk, props |
| **PETG** | Also fine. Slightly stronger; not required |

Antenna zone: keep plastic thin/light near the ESP32 ceramic antenna. No metal paint, no foil wrap "for aesthetics."

---

## Tolerance and "it doesn't fit"

The models are **prepared with clearance** so printed parts and hardware (servos, screws) are meant to **fit together** without sanding as the happy path. 3D printing is still approximate — holes shrink, first layers bulge ("elephant's foot"), printers vary.

**If a servo doesn't slide in:**
- Don't force it — gears aren't meant to take press-fit stress
- Ream with a drill bit by hand, or
- Sand lightly, or
- Open the pocket in CAD and re-export

> **If you've written backend code…** Printed holes are like JSON numbers — `2.0` isn't exactly 2.0 after float serialization. These files already budget slack; a badly calibrated printer can still eat it.

**Screws:** assembly uses **M2** screws that thread directly into the printed plastic — no glue, no heat-set inserts. Shopping list (M2×4 / ×8 / ×16 + nuts; same lengths for every servo preset) lives in the [3D models README](../../3d_models/README.md#screws). Join order: [assembly guide](../3d/assembly.md). Test fit as you go.

**If M2 screws feel loose (slide instead of cutting a thread):** print tolerances ate the pilot. Print [`ScrewSizingTest.3mf`](../../3d_models/README.md#print-first) first (alongside [`ServoSizingTester`](../../3d_models/README.md#print-first)), pick the labeled hole that bites firmly, set Fusion `screw_thread_diameter` to that diameter, and re-export. CAD default / shipped parts use **2.1 mm**. Full write-up: [M2 screw holes](../3d/parametric-design.md#m2-screw-holes).

---

## Editing the CAD — Fusion 360

### Source vs export

| File | What it is |
| --- | --- |
| [`cad/TinyEngineer.f3d`](../../3d_models/cad/TinyEngineer.f3d) | **Parametric source** — full assembly in Autodesk Fusion |
| [`3d_models/parts/{servo_id}/3mf/*.3mf`](../../3d_models/parts/) | **Exported meshes** — what the printer eats |

> **If you've written backend code…** `.f3d` is the repo. `.3mf` is the release binary. Don't edit `.3mf` as source — edit Fusion, re-export.

### When to open Fusion

- Servo pocket too tight/loose after first print
- Different micro servo dimensions (use a [`servos.json`](../../3d_models/fusion/TinyEngineerTools/servos.json) preset, or add one)
- Cable routing channel for your wiring harness
- Antenna keep-out adjustment
- Desk/chair scale for your desk

Parts use **M2** screws (`screw_thread_diameter` pilot). Servo pockets follow the selected Fusion preset, not one fixed body size. Swapping servos means picking a preset (or adding one) and reprinting — not just firmware. Servo user parameters, screw pilots, the Fusion add-in (configurator + exporter), and how to add a preset: [parametric design](../3d/parametric-design.md).

### Export workflow

1. Open `TinyEngineer.f3d` in Fusion (free personal license exists)
2. Apply a servo preset; set `screw_thread_diameter` from your [`ScrewSizingTest`](../../3d_models/README.md#print-first) if needed
3. Export with **Tiny Engineer Parts Exporter** into `parts/{servo_id}/3mf/` (see [parametric design](../3d/parametric-design.md))
4. Print testers first, then the rest, and test fit

Manual single-body export is fine for a one-off tweak; keep the file under that servo’s `3mf/` folder, not a flat `3d_models/parts/` dump.

Alternatives (FreeCAD, Onshape) can work but project source is Fusion.

---

## Mechanical assembly principles

Step-by-step SOP: [assembly.md](../3d/assembly.md). Use that guide for the build sequence; principles below cover key failure modes.

### Servo installation

- **Orientation matters** — spline exit direction must match linkage. Check before screwing pocket closed
- **Screw horn with servo at center** — boot firmware or `/test/servo` to 90° first
- **Don't over-tighten horn screw** — strips plastic hub

### Range of motion before closing shell

Command each joint through safe range ([robot-movement.md](../robot-movement.md)). Listen for buzzing (stall). Adjust horns or setup-AP min/max (NVS) before trapping servos in plastic.

### USB and service access

Leave the main control board USB-C reachable for reflash. You'll flash again. Trust me. The advanced path uses a 5993 in that same role — [wiring.md](../hardware/wiring.md).

### Antenna clearance

ESP32-C3-Zero ceramic antenna needs air. Don't bury it against metal or a thick plastic wall. Wi-Fi is the control plane for your agent.

### No glue policy

Screws only — disassembly for fixes. Like modular monolith vs ball of mud.

### Desk scene

Chair, desk, laptop, bell, lamp, mug — cosmetic storytelling. Print order doesn't matter much; prioritize robot body + servos for bring-up.

Part list: [3d_models/README.md](../../3d_models/README.md).

---

## Print while you wait — parallel path

Electronics can ship slow. Start printing **structural parts** (chest, head, chair) while reading [Ch. 04](04-buses-and-protocols.md). Connect and smoke at checklist [§3–4](../getting-started.md#3-connect) — still on the desk — then one assembly run. Parallelism beats serial idle time.

---

**Next:** [Power budgets and safety](07-power-budgets-and-safety.md)

**Reference:** [assembly.md](../3d/assembly.md) · [3d_models/README.md](../../3d_models/README.md) · [cad/TinyEngineer.f3d](../../3d_models/cad/TinyEngineer.f3d) · [parametric design](../3d/parametric-design.md) · [robot-movement.md](../robot-movement.md)

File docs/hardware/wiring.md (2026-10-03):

# Modular wiring (advanced)

The default build uses the [main control board](main-control-board.md). This page is for adding modules that board does not support: a separate PCA9685 breakout, a MAX98357A breakout, and an Adafruit 5993 USB-C breakout.

Build the harness **on the desk** ([getting-started](../getting-started.md) — after print, before flash). Seat it with [assembly-modular.md](../3d/assembly-modular.md), which replaces [assembly §12–§13](../3d/assembly.md#12-electronics-inside-the-desk).

**Why these nets exist:**

- Two voltage rails: **5 V** for servos and the amp; **3.3 V** for ESP32 GPIO, PCA9685 **VCC**, and OLED. Never jumper those together.
- PCA9685 **VCC** is logic; **V+** is servo power. Same chip, two jobs.
- OLED and PCA9685 share one I2C bus (SDA/SCL).
- Audio is I2S into the MAX98357A; the speaker is **BTL** — **SPK− is not ground**.
- Every module shares **GND**.

**Connect in this order (power last):**

1. Common **GND** to every module.
2. Signal wires: I2C (SDA/SCL), I2S (BCLK/LRC/DIN), USB D+/D−, PCA9685 OE (GP5 → OE).
3. Logic **3V3**: ESP32 **3V3** → PCA9685 **VCC** and OLED **VCC**.
4. **5 V** last: USB VBUS → ESP32 **5V**, PCA9685 **5V**, MAX98357A **Vin**. Leave servo leads unplugged until centering.

Source of truth for *what is connected to what*: [`docs/wiring/Tiny Engineer.drawio.png`](../wiring/Tiny%20Engineer.drawio.png) ([`.drawio`](../wiring/Tiny%20Engineer.drawio)).

Firmware GPIO numbers: [`include/pins.h`](../../include/pins.h) / [pinout.md](pinout.md). Diagram labels pads **GP0**…**GP21**; those are the same pins as GPIO0…GPIO21.

Diagram colour: **red** = 5 V, **blue** = GND, thin wires = signals.

## Pin names as drawn

| Diagram label | Same net / meaning |
| --- | --- |
| USB **5V** | +5V rail (Adafruit 5993 **VBUS**) |
| USB **GND** | Common **GND** |
| USB **D−** / **D+** | 5993 data → ESP32 **GP18** / **GP19** (may be omitted on PNG) |
| ESP32 **GP0** | GPIO0, I2C **SDA** |
| ESP32 **GP1** | GPIO1, I2C **SCL** |
| ESP32 **GP2** | GPIO2, I2S **BCLK** |
| ESP32 **GP3** | GPIO3, I2S **WS/LRC** |
| ESP32 **GP4** | GPIO4, I2S **DIN** |
| PCA9685 **5V** | Servo-power *input* from USB 5V |
| PCA9685 **V+** | Servo-power *output* to servo 5V |
| PCA9685 **VCC** | Logic **3V3** |
| OLED **SCL** | I2C **SCL** (Waveshare silkscreen; PNG may say **SCK**) |
| MAX98357A **Vin** | Amp **+5V** (**VIN**) |
| MAX98357A **LRC** | **WS/LRC** |

On Adafruit PCA9685, header/terminal **V+** is normally the same servo rail as the diagram’s PCA9685 **5V** pad. Do **not** treat PCA9685 **5V** as **VCC**.

## Connection table (as drawn)

| From | Pin | To | Pin | Purpose |
| --- | --- | --- | --- | --- |
| USB (5993) | 5V / VBUS | ESP32-C3-Zero | 5V | Board 5 V in |
| USB (5993) | 5V / VBUS | PCA9685 | 5V | Servo-rail in |
| USB (5993) | 5V / VBUS | MAX98357A | Vin | Amp power |
| USB (5993) | GND | ESP32-C3-Zero | GND | Common ground |
| USB (5993) | GND | PCA9685 | GND (logic/header side) | Common ground |
| USB (5993) | GND | OLED | GND | Common ground |
| USB (5993) | GND | MAX98357A | GND | Common ground |
| USB (5993) | D− | ESP32-C3-Zero | GP18 | Native USB D− (flash / CDC) |
| USB (5993) | D+ | ESP32-C3-Zero | GP19 | Native USB D+ (flash / CDC) |
| ESP32-C3-Zero | 3V3 | PCA9685 | VCC | PCA9685 logic |
| ESP32-C3-Zero | 3V3 | OLED | VCC | OLED power |
| ESP32-C3-Zero | GP0 | PCA9685 | SDA | I2C data |
| ESP32-C3-Zero | GP0 | OLED | SDA | I2C data (shared) |
| ESP32-C3-Zero | GP1 | PCA9685 | SCL | I2C clock |
| ESP32-C3-Zero | GP1 | OLED | SCL | I2C clock (shared; Waveshare silkscreen **SCL**; PNG may say **SCK**) |
| ESP32-C3-Zero | GP2 | MAX98357A | BCLK | I2S bit clock |
| ESP32-C3-Zero | GP3 | MAX98357A | LRC | I2S word select |
| ESP32-C3-Zero | GP4 | MAX98357A | DIN | I2S data |
| PCA9685 | PWM | Servo | SIG | Servo PWM |
| PCA9685 | V+ | Servo | 5V | Servo power |
| PCA9685 | GND (servo side) | Servo | GND | Servo ground |

**All modules must share a common ground.** USB GND is the star in the drawing (ESP32, PCA9685 header, OLED, MAX98357A). Servo GND returns through PCA9685 servo-side GND, which is the same ground net.

> [!WARNING]
> Never power the servos from the ESP32 3.3 V regulator. Diagram: servo **5V** ← PCA9685 **V+**; PCA9685 **VCC** ← ESP32 **3V3** only.

## Power (as drawn)

```
USB 5V
  → ESP32 5V
  → PCA9685 5V
  → MAX98357A Vin

PCA9685 V+
  → Servo 5V
```

```
ESP32 3V3
  → PCA9685 VCC
  → OLED VCC
```

```
USB GND
  → ESP32 GND
  → PCA9685 GND (header)
  → OLED GND
  → MAX98357A GND

PCA9685 GND (servo header)
  → Servo GND
```

USB block in the drawing is the Adafruit **5993** — robot **power** (VBUS/GND) and, when wired, **programming** (D+/D− → GP19/GP18). The PNG may show only 5V/GND; data wires are required for the single-USB design. See [interfaces.md](interfaces.md).

## I2C (as drawn)

Shared bus:

- ESP32 **GP0** → PCA9685 **SDA** and OLED **SDA**
- ESP32 **GP1** → PCA9685 **SCL** and OLED **SCL**

Addresses (firmware, not on the drawing): PCA9685 `0x40`, OLED `0x3C`. See [interfaces.md](interfaces.md).

## I2S (as drawn)

- ESP32 **GP2** → MAX98357A **BCLK**
- ESP32 **GP3** → MAX98357A **LRC**
- ESP32 **GP4** → MAX98357A **DIN**
- USB **5V** → MAX98357A **Vin**
- USB **GND** → MAX98357A **GND**

Drawn MAX98357A pads: **Vin**, **GND**, **BCLK**, **LRC**, **DIN** only.

## PCA9685 → servo (as drawn)

One generic **Servo** block:

| Servo | PCA9685 |
| --- | --- |
| SIG | PWM |
| 5V | V+ |
| GND | GND |

Firmware drives **channels 0–4** (`SERVO_SPECS` / `SERVO_HEAD`…`SERVO_BODY`). The drawing does not number the PWM header. Channel → joint: [robot-movement.md](../robot-movement.md) / [`include/servos.h`](../../include/servos.h).

## Pads drawn with no wires

ESP32-C3-Zero, unused in the PNG:

**GP6, GP7, GP8, GP9, GP10, GP20, GP21**

Wire **GP5** → PCA9685 **OE** (`PCA9685_OE_PIN`; active LOW). The base PNG may omit that wire — add it on the breadboard and on the Adafruit breakout OE pin. GP9 = BOOT, GP10 = onboard WS2812. GP18/GP19 = native USB — wire from 5993 D−/D+ even if the base PNG omits them. See [pinout.md](pinout.md).

MAX98357A **GAIN** / **SD** not wired (breakout defaults). **SPK+** / **SPK-** not drawn.

## Not on the drawing

Still part of the selected hardware; do not invent extra ESP32 GPIO for them.

| Item | Rule |
| --- | --- |
| Speaker | Terminals → MAX98357A **SPK+** and **SPK-** only |
| 4 extra analog micro servos | Same 3-wire pattern as the drawn servo, on PCA9685 PWM 0–4 |
| Adafruit 5993 D+/D− | Wire to ESP32 **GP19** / **GP18** for flash and CDC (single-USB design) |
| PCA9685 OE | Wire ESP32 **GP5** → PCA9685 **OE** (active LOW) |
| MAX98357A GAIN / SD | Not wired; leave breakout defaults |

> [!WARNING]
> MAX98357A output is BTL. **SPK- is not ground.** Never tie SPK- or SPK+ to GND. Never drive the speaker from ESP32 GPIO.

## USB connector (5993)

On this path the robot uses **one** USB-C connector: the Adafruit 5993.

| Net | 5993 | ESP32 |
| --- | --- | --- |
| +5V | **VBUS** | **5V** pad (and the shared +5V rail) |
| GND | **GND** | **GND** |
| USB D− | **D−** | **GPIO18** (native USB D−) |
| USB D+ | **D+** | **GPIO19** (native USB D+) |

| Connector | Role |
| --- | --- |
| Adafruit **5993** | Only robot USB-C: **VBUS/GND** (power) + **D+/D−** → GP19/GP18 (flash / serial CDC) |
| ESP32-C3-Zero onboard USB-C | Leave **unused** when 5993 data is wired (avoids dual 5 V feed) |

That one cable supplies robot power and programming / serial CDC (`ARDUINO_USB_MODE=1`, `ARDUINO_USB_CDC_ON_BOOT=1`, monitor 115200). For early bare-module flashing before 5993 data is wired, the onboard port is fine.

Adafruit 5993 is a USB Type-C vertical breakout (downstream). Two 5.1 kΩ CC resistors ask the upstream port for **5 V / up to ~1.5 A**. Whether 1.5 A actually arrives depends on the charger/port. Five HD-1370A servos at stall (~1.3 A @ 4.8 V) plus the rest of the robot leaves little safety margin on a 1.5 A USB source. SG90 stall is typically higher still.

- **5 V / ≥ 2 A**, with extra margin if several servos can move **while audio plays**.
- The 5993 does not raise the current ceiling above what the source and CC advertisement allow.
- The 5993 is **not** USB-PD voltage conversion. Feed it 5 V USB, or bypass it with a dedicated 5 V / ≥2 A PSU on the +5V and GND rails.

The drawing may show USB **5V** / **GND** only; also wire **D+/D−**.

See [interfaces.md](interfaces.md), [power.md](power.md).

## Assembly checks

1. Every **GND** in the PNG is one net (USB, ESP32, PCA9685 both sides, OLED, MAX98357A, servo).
2. PCA9685 **VCC** ≈ 3.3 V, PCA9685 **5V** / **V+** ≈ 5 V, those two nets **not** shorted.
3. OLED clock wire lands on Waveshare **SCL** (PNG may still say **SCK**).
4. I2S is GP2/GP3/GP4 → BCLK/LRC/DIN, not swapped with I2C.
5. Speaker (if fitted) is only SPK+/SPK-, which are **not** in the PNG.

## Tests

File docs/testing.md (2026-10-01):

# Tests

Host checks. These commands do not flash the board. GitHub Actions on `main` and PRs runs these same commands (firmware, packages, and PCB). On-device hardware: [hardware/testing.md](hardware/testing.md).

## Firmware

Unity on the host. Compiles `src/settings/validate.cpp` plus header-only helpers such as [`include/servos.h`](../include/servos.h).

```bash
pio test -e native
python3 scripts/test_audio_pack.py
```

`pio run` builds firmware. Native tests are **`pio test -e native`**, not `pio run -e native`. `scripts/test_audio_pack.py` checks the stock WAV copy and mod overlay (no PlatformIO, no hardware).

## OLED expressions

The optional [expression library](../lib/TinyEngineerExpressions/README.md) has deterministic asset checks and native renderer tests. These checks require Node 18+ and PlatformIO; they do not access hardware. On the robot, enable those faces with Config / `eyes_style=kaomoji` (default remains `classic`).

```bash
node scripts/expressions/generate.js --check
node scripts/expressions/test-assets.js
pio test -e native
pio run -e expression-demo
```

The `expression-demo` environment builds a separate OLED-only application without changing the default robot build. For a later bench test, follow its [wiring and upload notes](../lib/TinyEngineerExpressions/README.md#standalone-oled-demo), leave the separate servo supply off, and observe all 16 faces through a complete 48-second cycle. Report physical display results separately from host tests and compilation.

## Packages

Node 18+. No robot.

```bash
npm test --prefix packages/tiny-engineer-cursor
npm test --prefix packages/tiny-engineer-antigravity
npm test --prefix packages/tiny-engineer-claude-code
```

## PCB

KiCad 10 (`kicad-cli`). Stdlib Python only — no pip packages. ERC (errors), DRC (errors + schematic parity), and `expected-nets.yml` for every board under `hardware/boards/`.

```bash
python3 scripts/check_pcb.py
```

Optional: `python3 scripts/check_pcb.py main-control-board --report-dir artifacts/pcb`. Details: [pcb.md](pcb.md). On-device hardware: [hardware/testing.md](hardware/testing.md).

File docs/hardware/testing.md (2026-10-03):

# Hardware testing

Firmware is [`src/main.cpp`](../../src/main.cpp). Boot **inits** hardware and starts HTTP. Demos (OLED, tones, servo sweep) run on demand via REST. Helpers:

- [`src/hardware/rgb.cpp`](../../src/hardware/rgb.cpp)
- [`src/display/oled.cpp`](../../src/display/oled.cpp) (init/boot/test: `oled_init.cpp`, `oled_boot.cpp`, `oled_test.cpp`)
- [`src/network/wifi_connect.cpp`](../../src/network/wifi_connect.cpp)
- [`src/audio/audio.cpp`](../../src/audio/audio.cpp)
- [`src/hardware/pca9685_servos.cpp`](../../src/hardware/pca9685_servos.cpp)
- [`src/http/http_server.cpp`](../../src/http/http_server.cpp), [`src/http/test_handlers.cpp`](../../src/http/test_handlers.cpp)

Constants: [`include/pins.h`](../../include/pins.h). Wi-Fi credentials are saved in NVS and configured only in setup AP mode (first boot, or after factory reset + power-cycle). Servo min/max, RGB LED mapping (`rgb_order`), and OLED rotation (`oled_rotate_180`) are also setup-AP-only; factory reset keeps them.

Build/flash: [flash.md](../flash.md) (`pio run`, `pio run -t upload`, serial 115200). Physical board is **Waveshare ESP32-C3-Zero**; PlatformIO env name is `esp32-c3-devkitm-1`.

## What boot covers

| Subsystem | How |
| --- | --- |
| Built-in WS2812 | Green ready (GPIO10) |
| I2C init | `Wire.begin` on GPIO0/GPIO1 |
| PCA9685 | Probe `0x40` early; OE HIGH during init, park neutral, then OE LOW (`PCA9685_OE_WIRED`) |
| OLED | Probe `0x3C`, init (optional) |
| Wi-Fi | STA connect from saved NVS credentials, or setup AP `TinyEngineer-XXXX` when unset/failed; mDNS `{hostname}.local` after STA connect |
| MAX98357A / I2S | `I2S.begin` 44.1 kHz 16-bit stereo |
| Servos | Smooth move to mid (or sleep pose) at 35°/s |
| HTTP | Port 80 when STA connected, or on setup AP at `192.168.4.1` |
| Success | Dim green RGB during init; then animation LED (see below) |
| Fatal init failure | Red blink code on the WS2812 (see below) |

## Boot-failure blink codes

A fatal init failure halts boot and blinks the onboard WS2812 red. The number of
flashes before the long gap identifies the subsystem:

| Blinks | Meaning |
| --- | --- |
| 1 | PCA9685 not found on I2C `0x40` |
| 2 | MAX98357A / I2S init failed |

Each flash is 300 ms on, 300 ms off; the gap between repeats is 3 s, so the start of a
cycle is easy to find. Serial carries the same message, but the blink code is readable
with no cable attached — and with `serial_log` off (the default) the serial line is
silent, which makes the LED the only signal a first-boot board gives you.

## Expected boot sequence

1. Serial banner `TINY ENGINEER`
2. `Starting I2C` / `SDA = GP0` / `SCL = GP1`
3. `Checking PCA9685 at 0x40...` → **must** succeed; all channels parked at mid
4. `Checking OLED at 0x3C...` → found or `ERROR: OLED not found` (continues)
5. Settings load from NVS (`loading` = `progress` or `sleep_inertia`)
6. **Progress loading (default):** OLED progress steps (Display → WiFi → Servos → Audio → Storage → Ready), then large full-width IP (or `No IP`) for 3 s, then idle eyes
7. **Sleep inertia loading:** wakeup frame 0 during init (classic: closed lids; cover: black halves; kaomoji: Sleepy; dots: no circles). Smooth move to sleep pose if `welcome` is on. After init, wake plays from t=0: slow eye open + blinks (~5.5 s). Head/neck wave only if `welcome` is on; otherwise eyes only
8. `WIFI SETUP` on serial — connect OK + IP, open setup AP, or saved credentials failed (setup AP for reconfiguration)
9. `Starting MAX98357A` → `I2S OK`
10. `Centering servos` — smooth move to per-channel mid (progress path only; skipped if sleep pose already applied)
11. `ROBOT READY`
12. RGB fades to white over 1 s if `welcome` runs (Wi-Fi OK and setting enabled), or fades off if idle
13. If Wi-Fi OK: `HTTP: http://<ip>/`, `HTTP: http://tiny-engineer.local/`, and `/health` URLs on serial
14. If setup AP active: `HTTP setup: http://192.168.4.1/config` on serial; OLED rotates setup instructions

`loop()` pumps the HTTP server and updates animation RGB fades. No audio/OLED/servo/LED demos until a POST.

## Animation RGB

During normal operation the onboard WS2812 tracks the active animation (not boot green):

| Animation | LED |
| --- | --- |
| `typing`, `reading`, `thinking`, `welcome`, `ring`, `wakeup` | White |
| `attention`, `error`, `dead` | Pulsing red (10%↔100%, 1.5 s cycle) |
| `abort` | Solid red |
| `none`, `sleep` | Off |

State changes fade over **1 s** (see [`docs/api.md`](../api.md#rgb-led)). Trigger via `POST /anim?name=…` or agent hooks / CLIs.

OLED shows matching status strings when the panel is present (progress loading: WiFi step labels; sleep inertia: eyes only).

## HTTP tests

API reference: [`docs/api.md`](../api.md).

Base URL is the board IP or `http://tiny-engineer.local` (2.4 GHz STA). Tests have side effects — use **POST**, not GET.

```bash
# Health
curl http://tiny-engineer.local/health

# Tones 500 / 700 / 1000 Hz
curl -X POST http://tiny-engineer.local/test/audio

# OLED title / HELLO / X in a box
curl -X POST http://tiny-engineer.local/test/screen

# Servos mid → +0.5 → −0.5 → mid of saved range (channels 0–4)
curl -X POST http://tiny-engineer.local/test/movement

# Onboard WS2812 R → G → B → white → off, then back to current animation LED
curl -X POST http://tiny-engineer.local/test/led

# One servo smooth move to angle (~140°/s; index 0–4, angle 0–180)
curl -X POST "http://tiny-engineer.local/test/servo?index=0&angle=90"
```

| Method | Path | Body |
| --- | --- | --- |
| `GET` | `/` | HTML endpoint index |
| `GET` | `/auth` | Auth status (`ok`, `required`, `wifi_configured`, `provisioning`) — always public |
| `GET` | `/health` | Health JSON — full field list in [api.md](../api.md#get-health) |
| `GET` / `POST` | `/anim` | Current animation / start one (`name`, optional `interrupt`) — full params in [api.md](../api.md#post-anim) |
| `GET` | `/settings` | Persistent settings (`sleep_timeout`, `hostname`, `volume`, `welcome`, `serial_log`, `continuous_timeout`, `loading`, `eyes_style`, `access_token_set`, `wifi_configured`, `wifi_ssid`, `wifi_password_set`, `servo_mins`, `servo_maxs`, `rgb_order`, `oled_rotate_180`) |
| `POST` | `/settings?...&wifi_ssid=&wifi_password=` | Update NVS settings; WiFi params setup-AP-only and tested before save; `reboot_required` if hostname changed |
| `POST` | `/settings?...&servo_mins=&servo_maxs=` | Servo min/max comma lists; setup-AP-only |
| `POST` | `/settings?...&rgb_order=` | WS2812 byte order (`RGB`/`RBG`/`GRB`/`GBR`/`BRG`/`BGR`); setup-AP-only; default `GRB` |
| `POST` | `/settings?...&oled_rotate_180=` | OLED 180° rotation (`0`/`1`); setup-AP-only; default `0` |
| `POST` | `/settings/reset` | Factory reset settings to defaults (clears WiFi, keeps servo ranges, RGB mapping, and screen rotation); power-cycle to reopen setup AP |
| `POST` | `/test/audio` | `{"ok":true,"test":"audio"}` after `runSoundTest()` |
| `POST` | `/test/audio/bell` | `{"ok":true,"test":"bell"}` after `playBell()` |
| `POST` | `/test/screen` | `{"ok":true,"test":"screen"}` after `runOledTest()` |
| `POST` | `/test/movement` | `{"ok":true,"test":"movement"}` after `runServoTest()` |
| `POST` | `/test/led` | `{"ok":true,"test":"led"}` after `runRgbTest()` |
| `POST` | `/test/servo?index=&angle=` | `{"ok":true,"test":"servo","index":N,"angle":A}` after `moveServoSmooth()` |
| `POST` | `/setup/servo?all=90` or `?index=&angle=` | Setup AP only; slow 0–180° move (`SERVO_CALIB_SPEED_DEG_S`) |
| `POST` | `/setup/led?color=R` / `G` / `B` or `?byte=0` / `1` / `2` / `off` | Setup AP only; light logical RGB or one WS2812 wire byte, or release hold |
| `POST` | `/setup/audio` | Setup AP only; play `welcome.wav` (`playWelcome()`) |
| `POST` | `/setup/oled?rotate_180=0` / `1` | Setup AP only; preview OLED 180° rotation (`THIS WAY UP`); omit param to restore provisioning text |

GET on a test path returns `405`. Bad `/test/servo`, `/setup/servo`, `/setup/led`, `/setup/audio`, `/setup/oled`, or `/settings` params return `400`. Missing/wrong Bearer when auth enabled returns `401`. Control APIs return `503` when WiFi credentials are not saved (`/setup/servo`, `/setup/led`, `/setup/audio`, and `/setup/oled` stay available). Unknown path returns `404`. JSON `Content-Type`. Handlers block until the test finishes; the OLED returns to `ROBOT READY` after.

HTTP runs on STA when connected, or on setup AP at `192.168.4.1` during provisioning.

## Failures

| Serial / OLED | Meaning | Check |
| --- | --- | --- |
| OLED `ERROR: OLED not found` then rest of boot runs | Nothing ACK’d at `0x3C` | OLED **VCC=3V3**, GND, SDA=GP0, **SCL**=GP1, common ground, address jumper still 0x3C |
| OLED found but `ERROR: OLED initialization failed` | ACK then `display.begin` failed | Wiring/power glitch, wrong size module, I2C noise |
| OLED shows `Join this WiFi` / AP name, then `Then open` / `192.168.4.1` | Setup AP mode active | Connect to the shown AP, open `http://192.168.4.1/config`, finish the servo + screen + LED + speaker + WiFi wizard |
| OLED `WiFi failed` then setup AP | Saved STA credentials failed | Join setup AP, open `http://192.168.4.1/config`, enter home WiFi again |
| `ERROR: PCA9685 not found` + red RGB + **hang** | Nothing ACK’d at `0x40` | PCA9685 **VCC=3V3** (not V+), GND, SDA/SCL, I2C address pads, +5V not required for the ACK but needed later for motion |
| `ERROR: I2S initialization failed` + red RGB + **hang** | `I2S.begin` failed | GPIO2/3/4 not shorted to 5V/GND; pin constants; USB CDC still alive so you can read the line |
| I2S OK but `POST /test/audio` is silent | Amp or speaker | MAX98357A **Vin**=USB 5V, GND, GP2/3/4 → BCLK/LRC/DIN, speaker on **SPK+ / SPK-** (not on the PNG, not GND) |
| Servos silent / twitch / ESP32 resets during `POST /test/movement` | Power or SIG | **V+** is +5V, SIG on ch 0–4, **common GND**, supply current — see [power.md](power.md) |
| RGB never goes green | GPIO10 LED path | Board is C3-Zero (LED on GPIO10). Do not expect an external NeoPixel |

OLED absence and Wi-Fi failure are **soft** fails. PCA9685 and I2S failures **halt** in `while (true)`.

## Power during the servo test

All five servos move together on `POST /test/movement`. A weak USB port often dies **here**. If the serial port drops exactly when that POST runs: treat as brownout, not a PWM bug. Boot parks at each joint’s calibrated mid, which is much lighter.

## What this test does not prove

- That tuned mechanical limits match a particular physical build (start from `SERVO_SPECS`; adjust after assembly)
- BLE (out of scope)
- Speaker power rating vs max amp output
- I2C at high speed

Related: [main-control-board.md](main-control-board.md), [pinout.md](pinout.md), [servos.md](servos.md). Advanced harness: [wiring.md](wiring.md).

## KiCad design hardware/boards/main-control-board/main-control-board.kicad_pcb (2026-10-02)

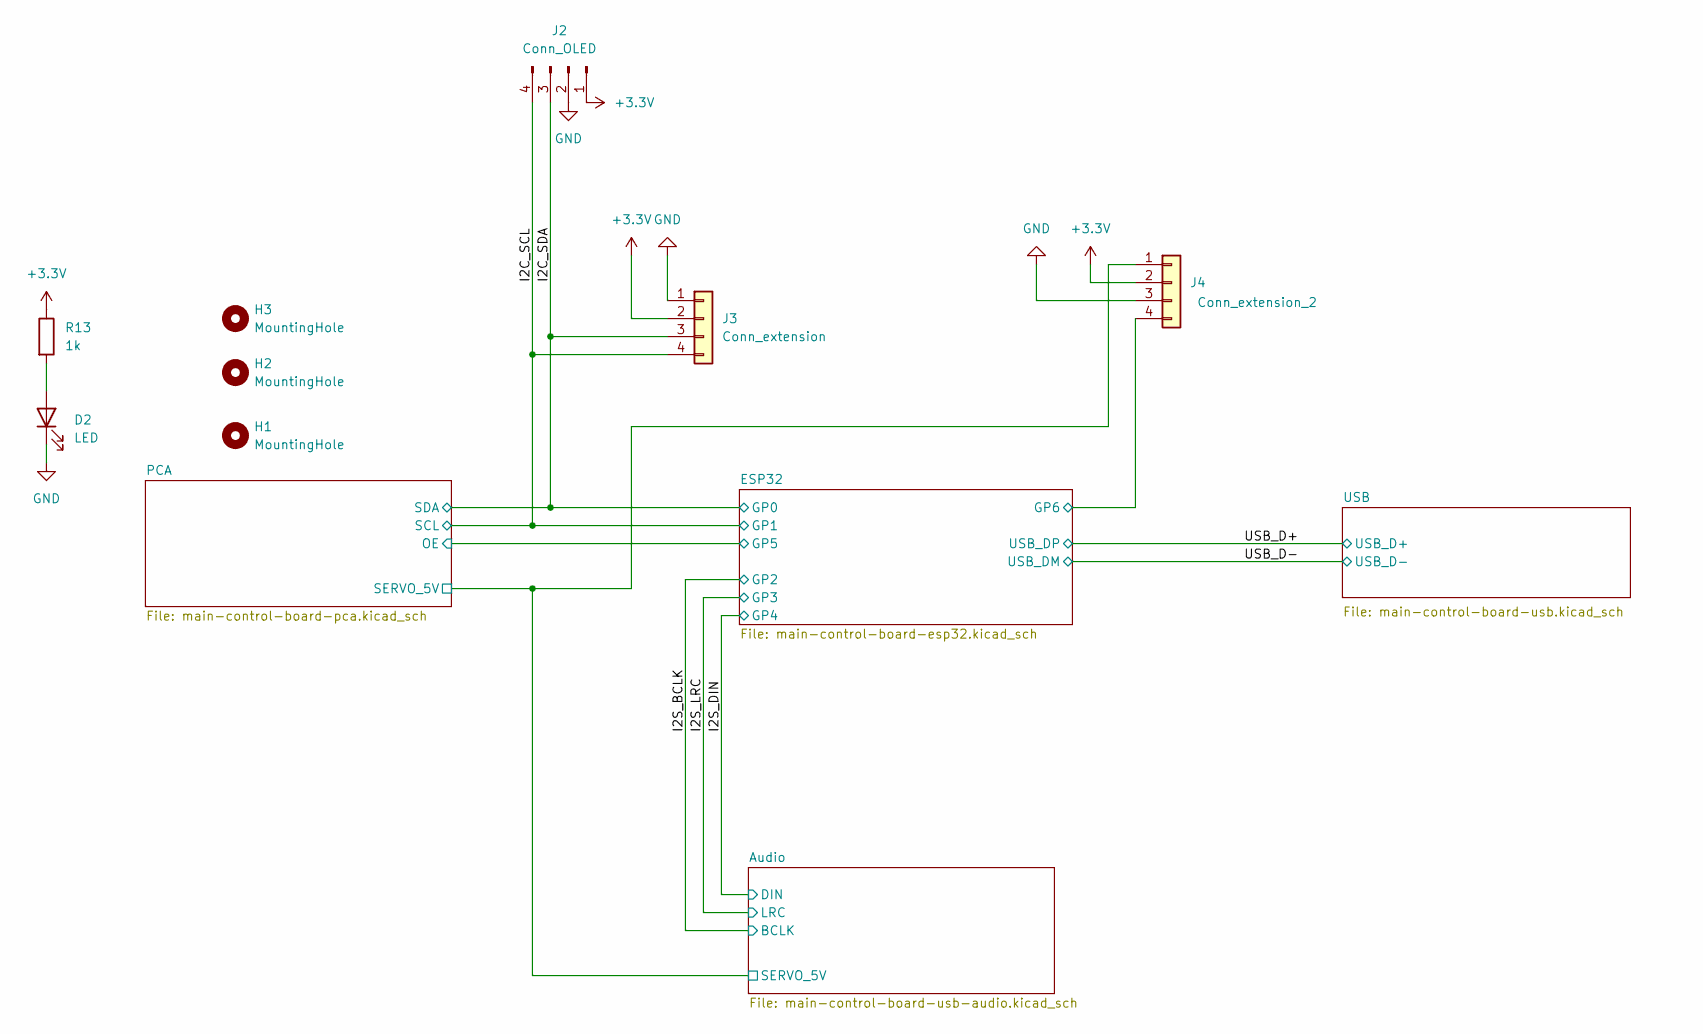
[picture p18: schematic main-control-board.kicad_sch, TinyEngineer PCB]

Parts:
D2: LED; LED_0603_1608Metric; LCSC Part # C2286
H1, H2, H3: MountingHole; MountingHole_2.2mm_M2
J2: Conn_OLED; PinHeader_1x04_P2.54mm_Vertical; LCSC Part # C2691448
J3: Conn_extension; JST_SH_SM04B-SRSS-TB_1x04-1MP_P1.00mm_Horizontal; LCSC Part # C160404
J4: Conn_extension_2; PinHeader_1x04_P2.54mm_Vertical
R13: 1k; R_0603_1608Metric; LCSC Part # C21190

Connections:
+3.3V: J2.1, J3.2, J4.2, R13.1; also elsewhere on the board
/ESP32/GP6: J4.4; also elsewhere on the board
/I2C_SCL: J2.4, J3.4; also elsewhere on the board
/I2C_SDA: J2.3, J3.3; also elsewhere on the board
/PCA/SERVO_5V: J4.1; also elsewhere on the board
GND: D2.1 (K), J2.2, J3.1, J4.3; also elsewhere on the board
unnamed: D2.2 (A), R13.2

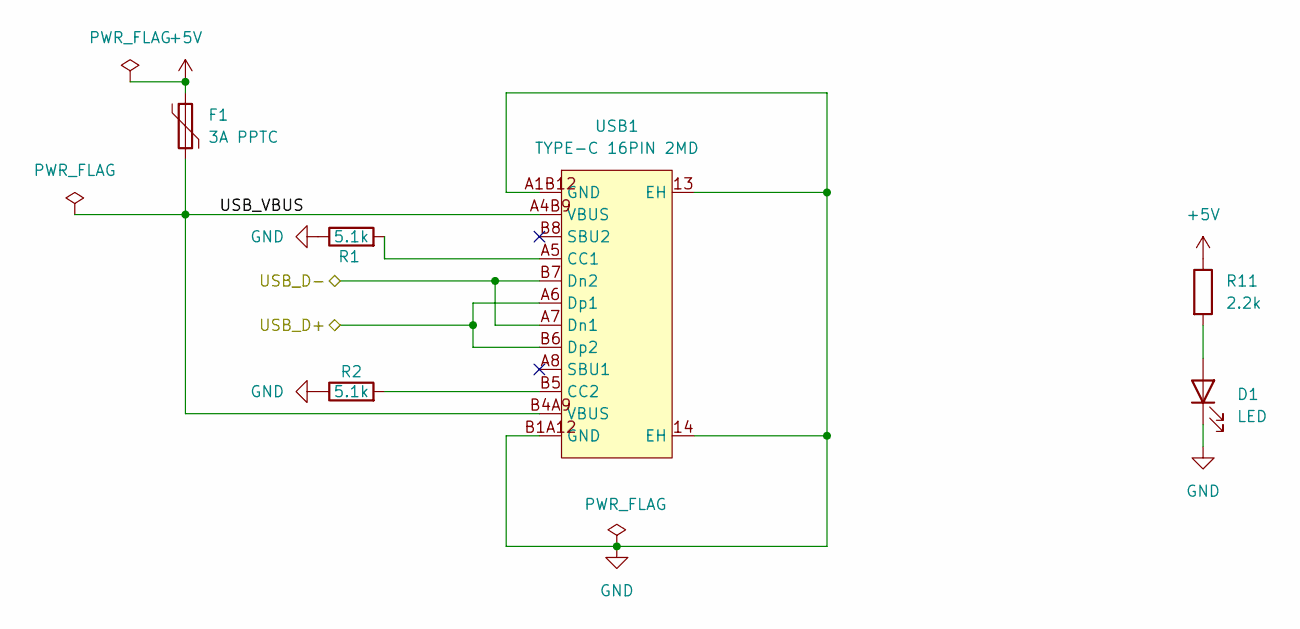
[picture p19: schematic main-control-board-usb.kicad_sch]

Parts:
D1: LED; LED_0603_1608Metric; LCSC Part # C2286
F1: 3A PPTC; Fuse_1812_4532Metric; LCSC Part # C883162
R1, R2: 5.1k; R_0603_1608Metric; LCSC Part # C23186
R11: 2.2k; R_0603_1608Metric; LCSC Part # C4190
USB1: TYPE-C 16PIN 2MD; USB-C-SMD_TYPE-C-16PIN-2MD-073; MPN TYPE-C 16PIN 2MD(073); LCSC Part # C2765186

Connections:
+5V: F1.1, R11.1; also elsewhere on the board
/USB/USB_VBUS: F1.2, USB1.A4B9 (VBUS), USB1.B4A9 (VBUS)
/USB_D+: USB1.A6 (Dp1), USB1.B6 (Dp2); also elsewhere on the board
/USB_D-: USB1.A7 (Dn1), USB1.B7 (Dn2); also elsewhere on the board
GND: D1.1 (K), R1.1, R2.1, USB1.13 (EH), USB1.14 (EH), USB1.A1B12 (GND), USB1.B1A12 (GND); also elsewhere on the board
unnamed: D1.2 (A), R11.2
unnamed: R1.2, USB1.A5 (CC1)
unnamed: R2.2, USB1.B5 (CC2)

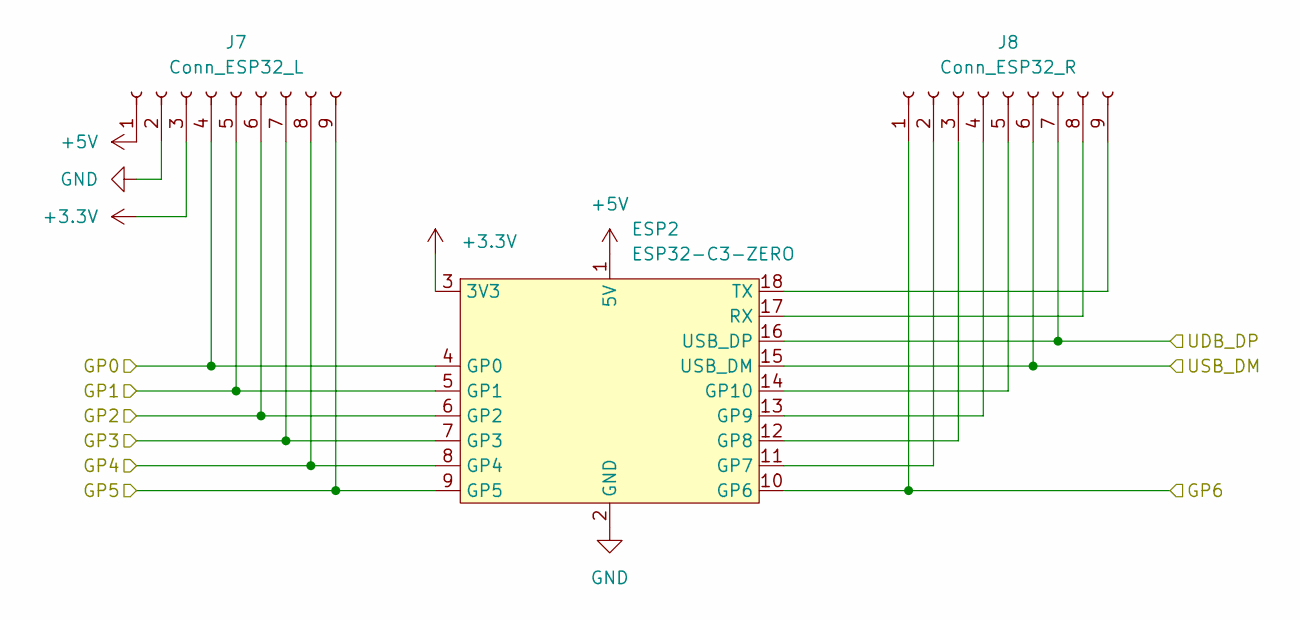
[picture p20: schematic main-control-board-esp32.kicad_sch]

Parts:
ESP2: ESP32-C3-ZERO; ESP32_C3_Zero_Dev_Board
J7: Conn_ESP32_L; PinSocket_1x09_P2.54mm_Vertical; LCSC Part # C2897372
J8: Conn_ESP32_R; PinSocket_1x09_P2.54mm_Vertical; LCSC Part # C2897372

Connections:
+3.3V: ESP2.3 (3V3), J7.3; also elsewhere on the board
+5V: ESP2.1 (5V), J7.1; also elsewhere on the board
/ESP32/GP5: ESP2.9 (GP5), J7.9; also elsewhere on the board
/ESP32/GP6: ESP2.10 (GP6), J8.1; also elsewhere on the board
/I2C_SCL: ESP2.5 (GP1), J7.5; also elsewhere on the board
/I2C_SDA: ESP2.4 (GP0), J7.4; also elsewhere on the board
/I2S_BCLK: ESP2.6 (GP2), J7.6; also elsewhere on the board
/I2S_DIN: ESP2.8 (GP4), J7.8; also elsewhere on the board
/I2S_LRC: ESP2.7 (GP3), J7.7; also elsewhere on the board
/USB_D+: ESP2.16 (USB_DP), J8.7; also elsewhere on the board
/USB_D-: ESP2.15 (USB_DM), J8.6; also elsewhere on the board
GND: ESP2.2 (GND), J7.2; also elsewhere on the board
unnamed: ESP2.11 (GP7), J8.2
unnamed: ESP2.12 (GP8), J8.3
unnamed: ESP2.13 (GP9), J8.4
unnamed: ESP2.14 (GP10), J8.5
unnamed: ESP2.17 (RX), J8.8
unnamed: ESP2.18 (TX), J8.9

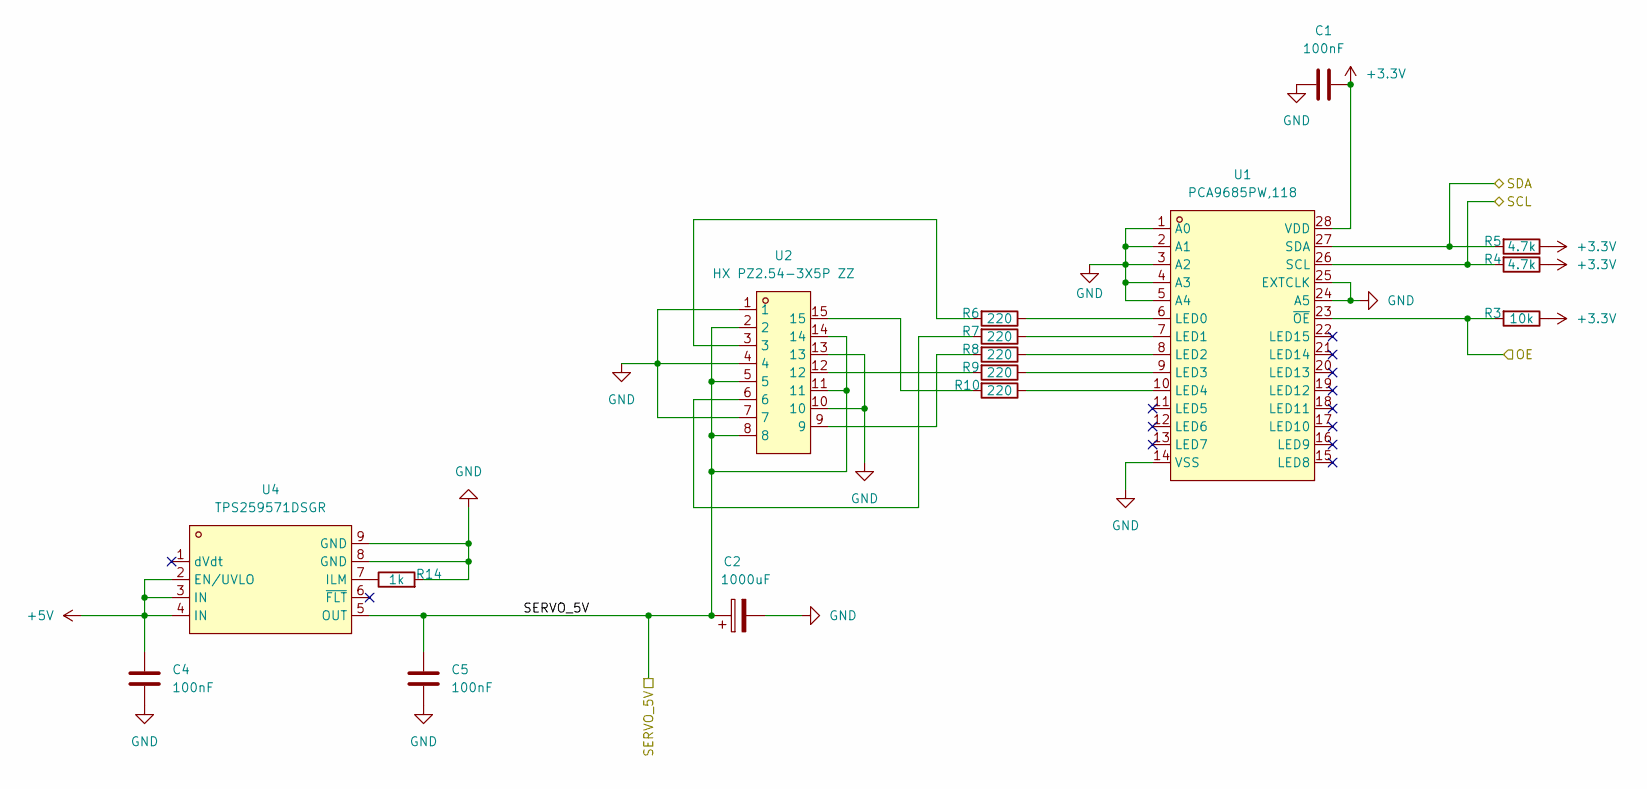
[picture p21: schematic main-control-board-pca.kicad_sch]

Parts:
C1, C4, C5: 100nF; C_0603_1608Metric; LCSC Part # C14663
C2: 1000uF; CP_Elec_10x10.5; LCSC Part # C46550395
R3: 10k; R_0603_1608Metric; LCSC Part # C25804
R4, R5: 4.7k; R_0603_1608Metric; LCSC Part # C23162
R6, R7, R8, R9, R10: 220; R_0603_1608Metric; LCSC Part # C22962
R14: 1k; R_0603_1608Metric; LCSC Part # C21190
U1: PCA9685PW,118; TSSOP-28_L9.7-W4.4-P0.65-LS6.4-TL; MPN PCA9685PW,118; LCSC Part # C2678753
U2: HX PZ2.54-3X5P ZZ; HDR-TH_15P-P2.54-V-M-R3-C5-S7.5; MPN HX PZ2.54-3x5P ZZ; LCSC Part # C32713292
U4: TPS259571DSGR; WSON-8_L2.0-W2.0-P0.50-TL-EP; MPN TPS259571DSGR; LCSC Part # C471038

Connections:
+3.3V: C1.2, R3.1, R4.1, R5.1, U1.28 (VDD); also elsewhere on the board
+5V: C4.2, U4.2 (EN/UVLO), U4.3 (IN), U4.4 (IN); also elsewhere on the board
/ESP32/GP5: R3.2, U1.23 (~OE); also elsewhere on the board
/I2C_SCL: R4.2, U1.26 (SCL); also elsewhere on the board
/I2C_SDA: R5.2, U1.27 (SDA); also elsewhere on the board
/PCA/SERVO_5V: C2.1, C5.2, U2.2, U2.5, U2.8, U2.11, U2.14, U4.5 (OUT); also elsewhere on the board
GND: C1.1, C2.2, C4.1, C5.1, R14.2, U1.1 (A0), U1.2 (A1), U1.3 (A2), U1.4 (A3), U1.5 (A4), U1.14 (VSS), U1.24 (A5), U1.25 (EXTCLK), U2.1, U2.4, U2.7, U2.10, U2.13, U4.8 (GND), U4.9 (GND); also elsewhere on the board
unnamed: R6.2, U2.3
unnamed: R7.2, U2.6
unnamed: R8.2, U2.9
unnamed: R9.2, U2.12
unnamed: R10.2, U2.15
unnamed: R6.1, U1.6 (LED0)
unnamed: R7.1, U1.7 (LED1)
unnamed: R8.1, U1.8 (LED2)
unnamed: R9.1, U1.9 (LED3)
unnamed: R10.1, U1.10 (LED4)
unnamed: R14.1, U4.7 (ILM)

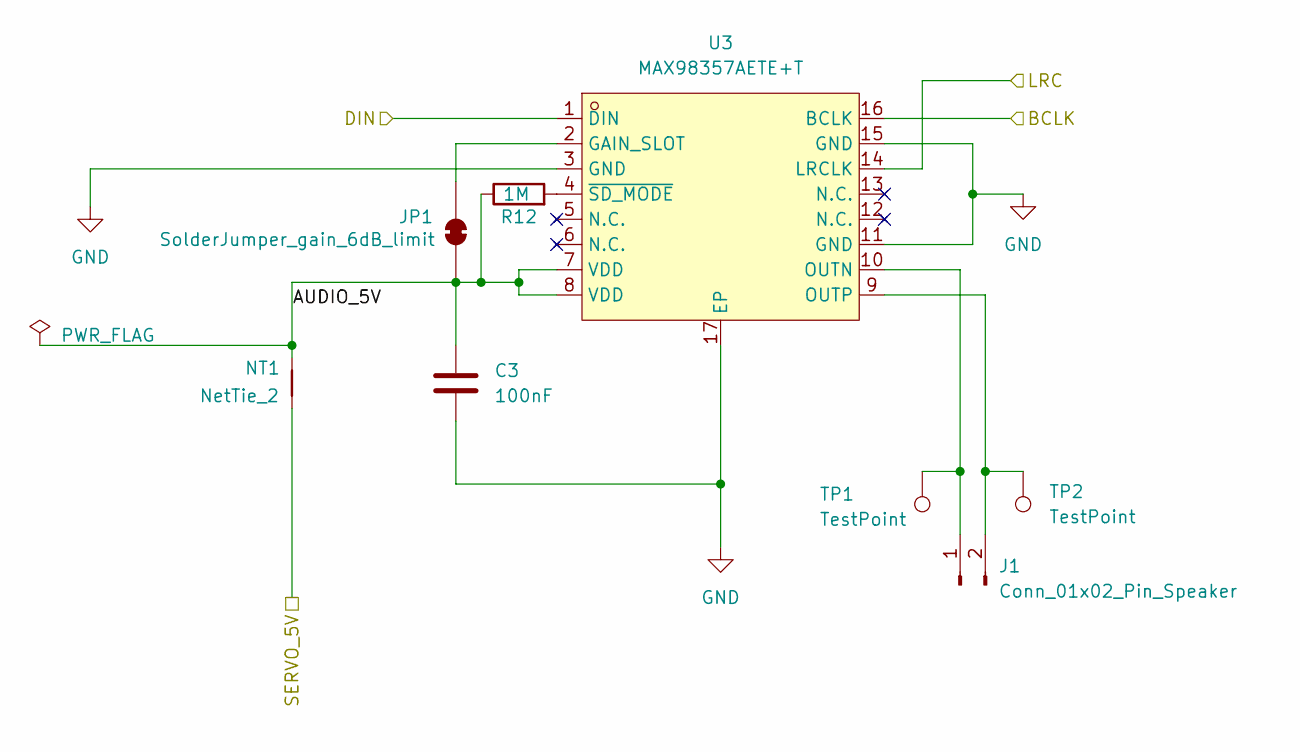
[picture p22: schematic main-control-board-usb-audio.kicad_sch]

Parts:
C3: 100nF; C_0603_1608Metric; LCSC Part # C14663
J1: Conn_01x02_Pin_Speaker; Molex_PicoBlade_53261-0271_1x02-1MP_P1.25mm_Horizontal; LCSC Part # C2845379
JP1: SolderJumper_gain_6dB_limit; SolderJumper-2_P1.3mm_Bridged_RoundedPad1.0x1.5mm
NT1: NetTie_2; NetTie-2_SMD_Pad2.0mm
R12: 1M; R_0603_1608Metric; LCSC Part # C22935
TP1, TP2: TestPoint; SolderWire-0.25sqmm_1x01_D0.65mm_OD2mm
U3: MAX98357AETE+T; TQFN-16_L3.0-W3.0-P0.50-BL-EP1.5; MPN MAX98357AETE+T; LCSC Part # C910544

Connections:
/Audio/AUDIO_5V: C3.2, JP1.1 (A), NT1.2, R12.1, U3.7 (VDD), U3.8 (VDD)
/I2S_BCLK: U3.16 (BCLK); also elsewhere on the board
/I2S_DIN: U3.1 (DIN); also elsewhere on the board
/I2S_LRC: U3.14 (LRCLK); also elsewhere on the board
/PCA/SERVO_5V: NT1.1; also elsewhere on the board
GND: C3.1, U3.3 (GND), U3.11 (GND), U3.15 (GND), U3.17 (EP); also elsewhere on the board
unnamed: J1.1, TP1.1 (1_1), U3.10 (OUTN)
unnamed: J1.2, TP2.1 (1_1), U3.9 (OUTP)
unnamed: JP1.2 (B), U3.2 (GAIN_SLOT)
unnamed: R12.2, U3.4 (~SD_MODE)

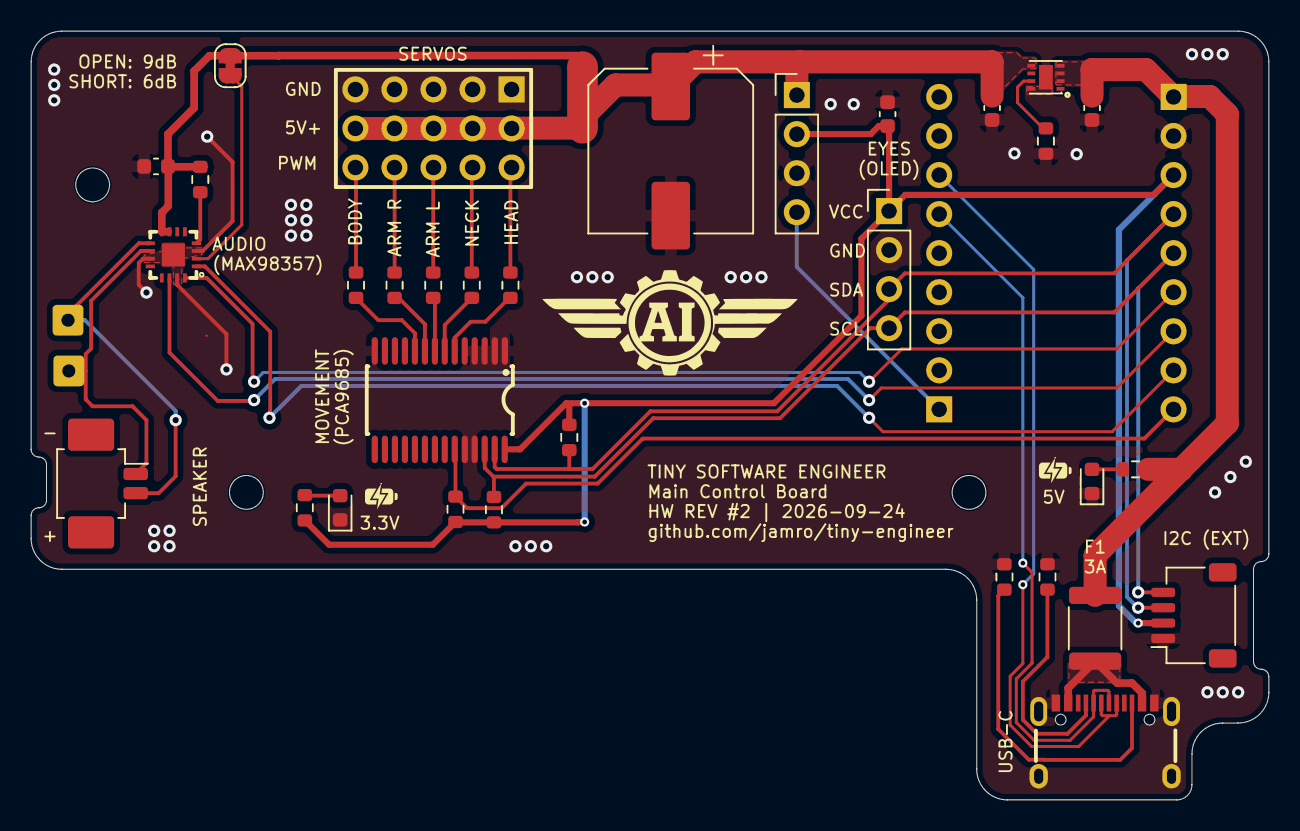
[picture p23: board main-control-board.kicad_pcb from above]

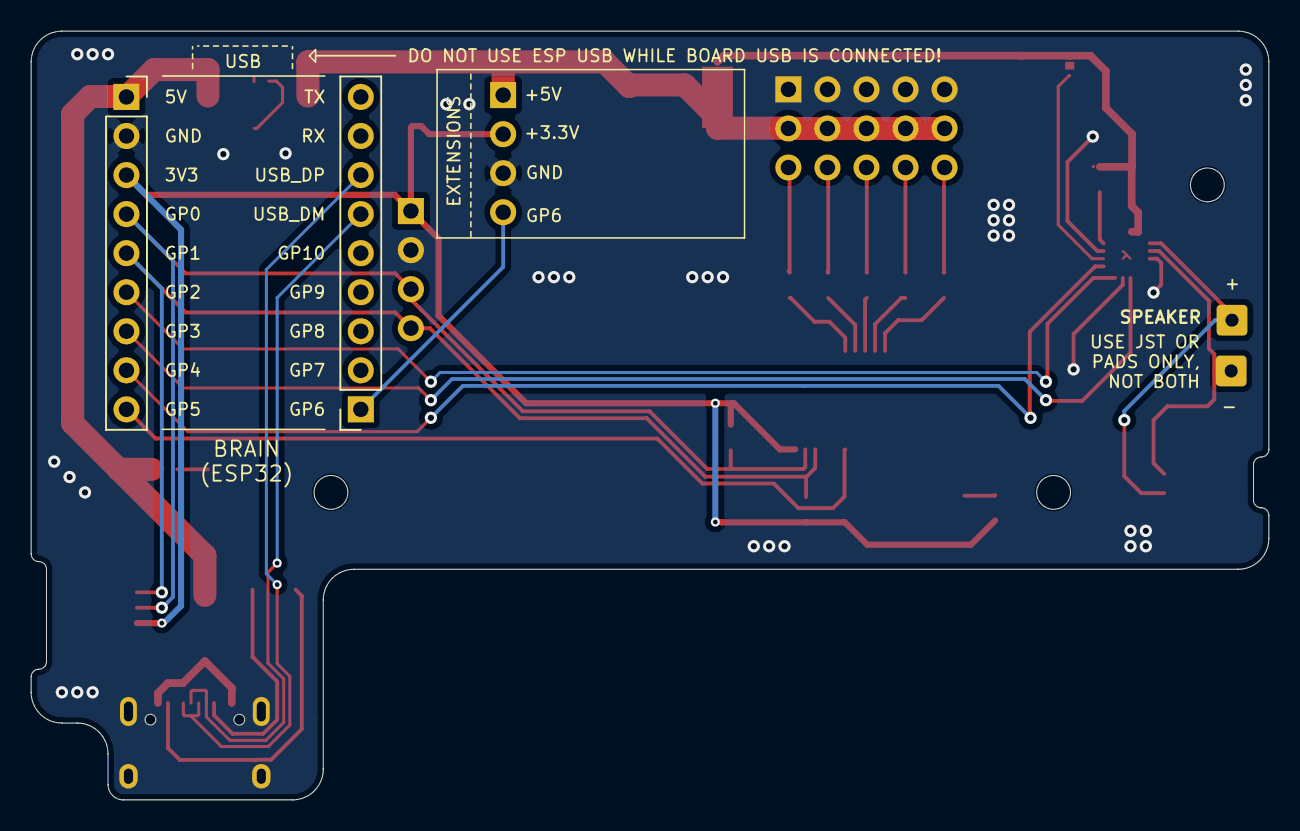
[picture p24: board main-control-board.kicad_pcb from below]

Board: 2 copper layers, 80.5 x 50.0 mm, 40 parts (2 on the bottom side), 34 nets.

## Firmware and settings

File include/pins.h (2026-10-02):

#pragma once

#include <cstdint>

// =====================================================
// PINOUT
// =====================================================

// I2C -> PCA9685 + OLED
constexpr int I2C_SDA = 0;   // GP0
constexpr int I2C_SCL = 1;   // GP1

// I2S -> MAX98357A
constexpr int I2S_BCLK = 2;  // GP2
constexpr int I2S_LRC  = 3;  // GP3
constexpr int I2S_DIN  = 4;  // GP4

// Built-in WS2812 RGB
constexpr int RGB_LED_PIN = 10;

// PCA9685 output enable (active LOW). GP5 → OE; default on.
// Set PCA9685_OE_WIRED false only if OE is hard-tied off-chip (e.g. to GND).
constexpr bool PCA9685_OE_WIRED = true;
constexpr int PCA9685_OE_PIN = 5;

// =====================================================
// AUDIO
// =====================================================

constexpr int SAMPLE_RATE = 44100;

// =====================================================
// PCA9685 / SERVOS
// =====================================================

constexpr uint8_t PCA9685_ADDRESS = 0x40;

constexpr int SERVO_STEP_MS = 10;

// Boot centering / sleep-pose rate (deg/s)
constexpr float SERVO_BOOT_SPEED_DEG_S = 35.0f;

// Servo pulse range
constexpr int SERVO_MIN_US = 800;
constexpr int SERVO_MAX_US = 2200;

// =====================================================
// OLED
// =====================================================

constexpr int OLED_WIDTH  = 128;
constexpr int OLED_HEIGHT = 32;
constexpr uint8_t OLED_ADDRESS = 0x3C;

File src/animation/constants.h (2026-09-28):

#pragma once

#include <cstdint>

namespace anim {

// Pose units are -1..1 (saved min / mid / max). Speeds stay deg/s.

constexpr float TYPING_HAND_BAND = 1.0f / 3.0f;
constexpr float TYPING_HEAD_BAND = 2.0f / 7.0f;
constexpr float TYPING_SWAY = 1.0f / 9.0f;
constexpr float READING_HEAD_BAND = 2.0f / 7.0f;
constexpr float READING_NECK_SWAY = 2.0f / 9.0f;

constexpr float TRANSITION_TORSO_SPEED_DEG_S = 25.0f;
constexpr float TRANSITION_HAND_SPEED_DEG_S = 90.0f;

constexpr float TYPING_RIGHT_LOW = -1.0f;
constexpr float TYPING_RIGHT_HIGH = TYPING_RIGHT_LOW + TYPING_HAND_BAND;
constexpr float TYPING_LEFT_HIGH = 1.0f;
constexpr float TYPING_LEFT_LOW = TYPING_LEFT_HIGH - TYPING_HAND_BAND;

constexpr float TYPING_HEAD_LOW = -1.0f;
constexpr float TYPING_HEAD_HIGH = TYPING_HEAD_LOW + TYPING_HEAD_BAND;

constexpr float TYPING_BODY_MID = 0.0f;
constexpr float TYPING_NECK_MID = 0.0f;

constexpr float READING_HEAD_LOW = -1.0f;
constexpr float READING_HEAD_HIGH = READING_HEAD_LOW + READING_HEAD_BAND;
constexpr float READING_NECK_MID = 0.0f;

constexpr float RING_HEAD_START = 2.0f / 7.0f;
constexpr float RING_BODY_START = -1.0f;
constexpr float RING_RIGHT_START = 1.0f;
constexpr float RING_LEFT_START = 7.0f / 9.0f;
constexpr float RING_NECK_START = 0.0f;
constexpr float RING_RIGHT_STRIKE = -8.0f / 9.0f;
constexpr float RING_RIGHT_BOUNCE = -5.0f / 9.0f;
constexpr float RING_HEAD_STRIKE = -1.0f;

constexpr float WELCOME_HEAD_UP = 2.0f / 7.0f;
constexpr float WELCOME_HEAD_MID = 0.0f;
constexpr float WELCOME_HAND_REST = -1.0f;
constexpr float WELCOME_HAND_RAISED = 1.0f;
constexpr float WELCOME_HAND_WIGGLE = 8.0f / 45.0f;
constexpr float WELCOME_HEAD_NOD = 3.0f / 35.0f;

constexpr float ATTENTION_BODY_MID = 0.0f;
constexpr float ATTENTION_NECK_MID = 0.0f;
constexpr float ATTENTION_HEAD_READY = 6.0f / 35.0f;
constexpr float ATTENTION_HAND_LEFT_PARKED = 1.0f;
constexpr float ATTENTION_HAND_RIGHT_REST = -1.0f;
constexpr float ATTENTION_HAND_RIGHT_RAISED = 1.0f / 15.0f;
constexpr float ATTENTION_HAND_POINT = 1.0f / 3.0f;
constexpr float ATTENTION_HUMAN_NECK_GLANCE = 4.0f / 45.0f;
constexpr float ATTENTION_HUMAN_HEAD_NOD = 2.0f / 35.0f;
constexpr float ATTENTION_LOOK_NECK_GLANCE = 2.0f / 15.0f;
constexpr float ATTENTION_LOOK_HEAD_NOD = 2.0f / 35.0f;
constexpr float ATTENTION_WAIT_HEAD_NOD = 3.0f / 35.0f;
constexpr float ATTENTION_WAIT_NECK_TILT = 4.0f / 45.0f;
constexpr float ATTENTION_WAIT_HAND_WAVE = 7.0f / 45.0f;

// Attention/error wait after audio before auto-finish to none.
constexpr uint32_t NON_CONTINUOUS_HOLD_MS = 60UL * 1000UL;

constexpr float ERROR_BODY_TASK_SIDE = -8.0f / 45.0f;
constexpr float ERROR_NECK_TASK_SIDE = -2.0f / 9.0f;
constexpr float ERROR_HEAD_CONCERNED = -12.0f / 35.0f;
constexpr float ERROR_HAND_RIGHT_PRESENT = 13.0f / 45.0f;
constexpr float ERROR_HAND_LEFT_TASK_POINT = 23.0f / 45.0f;
constexpr float ERROR_HELP_NECK_GLANCE = 2.0f / 9.0f;
constexpr float ERROR_AWAY_NECK_GLANCE = 4.0f / 45.0f;
constexpr float ERROR_HELP_HEAD_GLANCE = 3.0f / 35.0f;
constexpr float ERROR_WORRY_HEAD_NOD = 2.0f / 35.0f;

constexpr float ABORT_BODY_DISMISSIVE = -1.0f / 9.0f;
constexpr float ABORT_NECK_SIDE = 14.0f / 45.0f;
constexpr float ABORT_NECK_OTHER_SIDE = -2.0f / 15.0f;
constexpr float ABORT_HEAD_UP = 16.0f / 35.0f;
constexpr float ABORT_HEAD_DIP = 1.0f / 7.0f;
constexpr float ABORT_HEAD_DIDNT_WANT = 12.0f / 35.0f;
constexpr float ABORT_HEAD_ANYWAY = 18.0f / 35.0f;

// Idle sleep / boot sleep-inertia: chin down, then rise to mid on wake.
constexpr float SLEEP_HEAD_DOWN = -4.0f / 7.0f;
constexpr float SLEEP_HEAD_AWAKE = 0.0f;
constexpr uint32_t SLEEP_NOD_OFF_MS = 2000;
constexpr float ABORT_HAND_RIGHT_UP = 1.0f;
constexpr float ABORT_HAND_RIGHT_SHRUG = 7.0f / 9.0f;
constexpr float ABORT_HAND_LEFT_UP = -2.0f / 9.0f;
constexpr float ABORT_HAND_LEFT_SHRUG = 2.0f / 45.0f;

// Power-loss collapse: chin fully down, hands parked.
constexpr float DEAD_HEAD_DOWN = -1.0f;

}  // namespace anim

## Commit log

2026-09-27 feat(firmware): introduce 'cover' eye style for OLED display
    - Added a new eye style called 'cover' that displays full-half bars for a mask with eye holes, enhancing visual options.
    - Updated documentation to reflect the new eye style and its behavior.
    - Modified related settings and validation to support the new style in the configuration.
    - Ensured compatibility with existing eye styles and updated UI elements accordingly.
2026-09-27 docs: add information about upcoming assembled Main Board in README
2026-09-27 docs: update contribution guidelines to include new 'mods' scope for CAD modifications
2026-09-29 feat(cad): add a parametric bottom cover and chair mounts (#49)
    [BottomCover.3mf, BottomCover.step, BottomCover.stl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]
2026-09-29 refctor(cad): simplify bottom cover design
    [AiEmblem.3mf, AiEmblem.step, AiEmblem.stl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]
2026-10-01 feat(mods): add hallowing pumpkin head example (#51)
    [Head.3mf, Head.step, Head.stl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]
2026-10-01 fix(mod): remove duplicated f3d halloween model
    [TinyEngineerHalloween.f3d]
2026-10-02 fix(cad): Keyboard keys may not extrude after increasing servo size #31
    change in laptop case gemoetry
    [DeskTop.3mf, DeskTop.step, DeskTop.stl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]
2026-10-02 reshape the board to mount SDM USB
    [main-control-board.kicad_pcb, main-control-board.kicad_sch]
2026-10-02 use hierarchical sheets in schmatic
    [main-control-board-esp32.kicad_sch, main-control-board-pca.kicad_sch, main-control-board-usb-audio.kicad_sch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]
2026-10-02 integrate PCA into the board
    [main-control-board-esp32.kicad_sch, main-control-board-pca.kicad_sch, main-control-board-usb.kicad_sch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]
2026-10-02 add power indicator
    [main-control-board-usb.kicad_sch, main-control-board.kicad_pcb]
2026-10-02 set FT Rotation Offset to fix JLCPCB orientation
    [main-control-board-esp32.kicad_sch, main-control-board-pca.kicad_sch, main-control-board.kicad_pcb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]
2026-10-02 integrate audio module
    [main-control-board-usb-audio.kicad_sch, main-control-board.kicad_pcb]
2026-10-02 improve board visuals
    [main-control-board-usb-audio.kicad_sch, main-control-board.kicad_pcb]
2026-10-02 add I2C extension port
    [main-control-board-usb-audio.kicad_sch, main-control-board.kicad_pcb, main-control-board.kicad_sch]
2026-10-02 use basic components over extended
    [main-control-board-pca.kicad_sch, main-control-board-usb-audio.kicad_sch, main-control-board-usb.kicad_sch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]
2026-10-02 add polyfuse protection
    [main-control-board-usb-audio.kicad_sch, main-control-board-usb.kicad_sch, main-control-board.kicad_pcb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]
2026-10-02 turn test points into extension points
    [main-control-board-esp32.kicad_sch, main-control-board.kicad_pcb, main-control-board.kicad_sch]
2026-10-02 pre-fab improvements
    [main-control-board-esp32.kicad_sch, main-control-board-pca.kicad_sch, main-control-board-usb-audio.kicad_sch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]
2026-10-02 fix expected nets
    [main-control-board.kicad_pcb, main-control-board.kicad_sch]
2026-10-02 fix check pcb
2026-10-02 update line coordinates in main control board PCB and footprint files for improved alignment
    [main-control-board.kicad_pcb]
2026-10-02 update line coordinates in TSSOP-28 footprint and main control board PCB for consistency and alignment
    [main-control-board.kicad_pcb]
2026-10-02 add efuse before 5V servo rail
    [main-control-board-pca.kicad_sch, main-control-board-usb-audio.kicad_sch, main-control-board.kicad_pcb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]
2026-10-02 clarify handling of lookup failures in JLCPCB BOM verification process
2026-10-02 fix(firmware): update PCA9685 output enable handling in documentation and code; set `PCA9685_OE_WIRED` to true, reflecting active LOW configuration for GP5
    [pins.h]
2026-10-02 docs: enhance documentation for electronics paths: introduce main control board option, update wiring and assembly instructions, and clarify shopping guide for modular vs. integrated builds
2026-10-02 docs(pcb): add ordering guide for main control board, including JLCPCB walkthrough
2026-10-03 feat(cad): adjust desk model to be compatible with main control board
    [AiEmblem.3mf, AiEmblem.step, AiEmblem.stl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]
2026-10-03 fix(cad): fix gemotery of pcb holder in desk
    [Desk.3mf, Desk.step, Desk.stl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]
2026-10-03 docs(pcb): main control board is the default path now
